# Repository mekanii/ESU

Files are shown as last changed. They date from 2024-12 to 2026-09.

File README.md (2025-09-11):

# 1. General Concept
<p align="center">
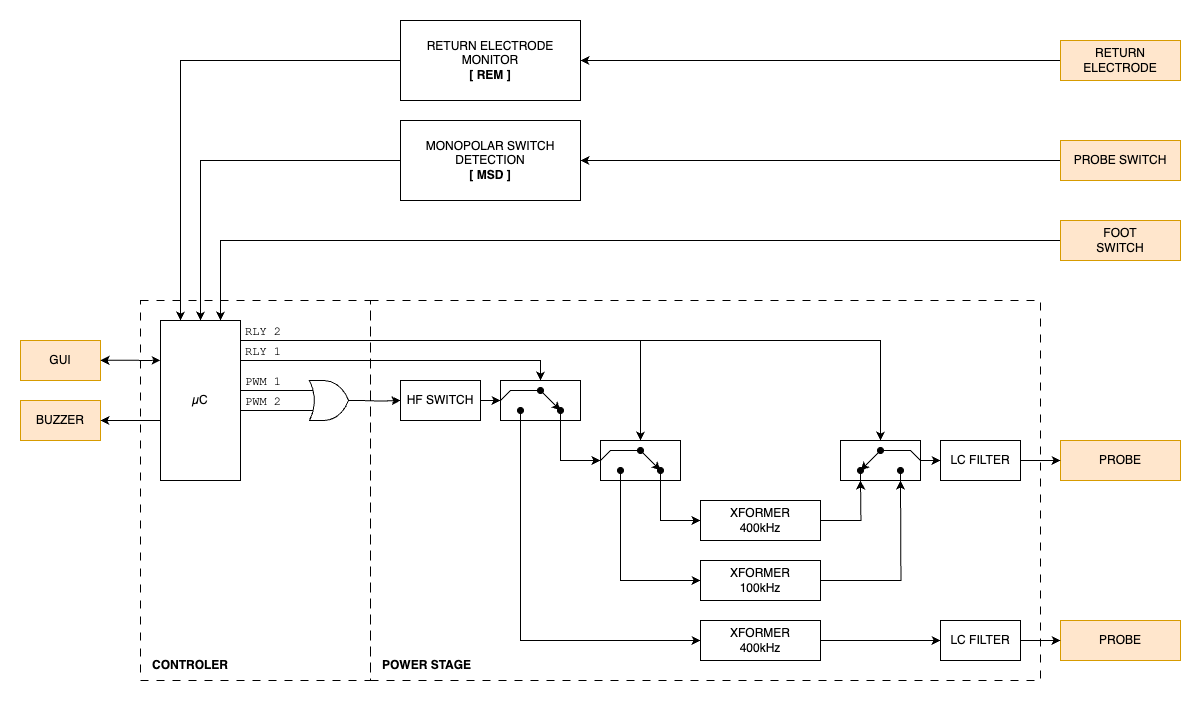
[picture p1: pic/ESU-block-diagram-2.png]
esu-block-diagram
  
</p>

<p align="center">
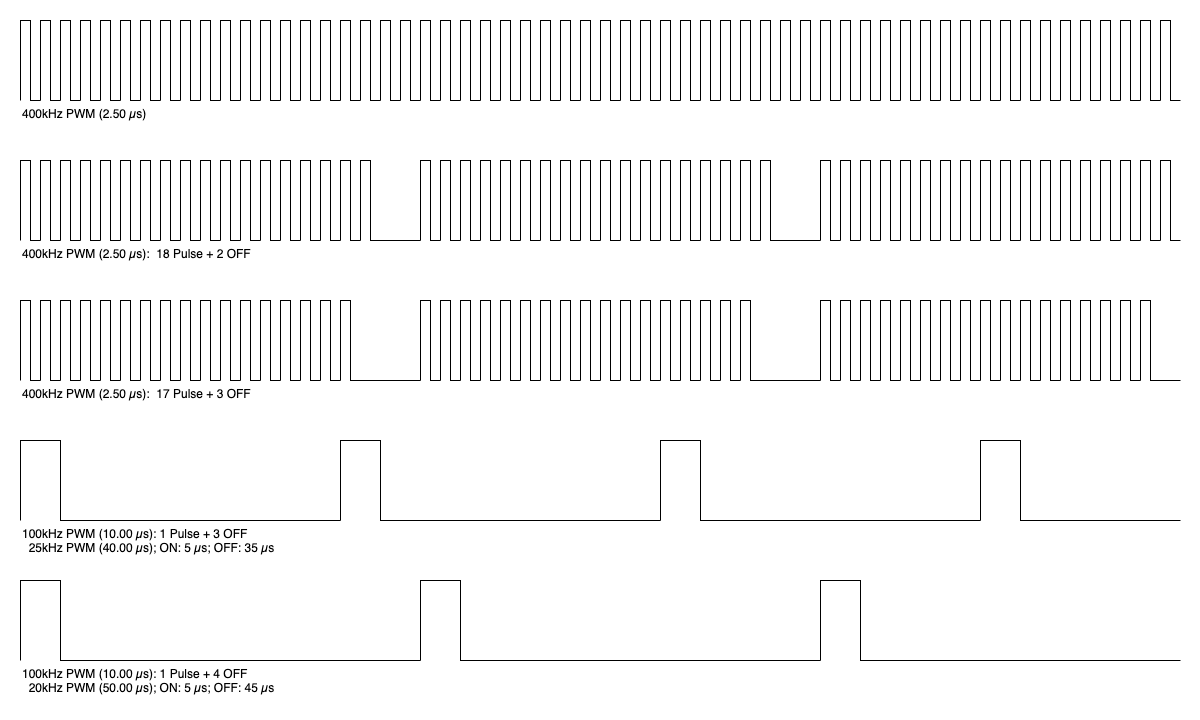
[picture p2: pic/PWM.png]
pwm
  
</p>

# 2. Component
## 2.1. Monopolar Switch Detection (MSD)
### 2.1.1. Schematic

<p align="center">
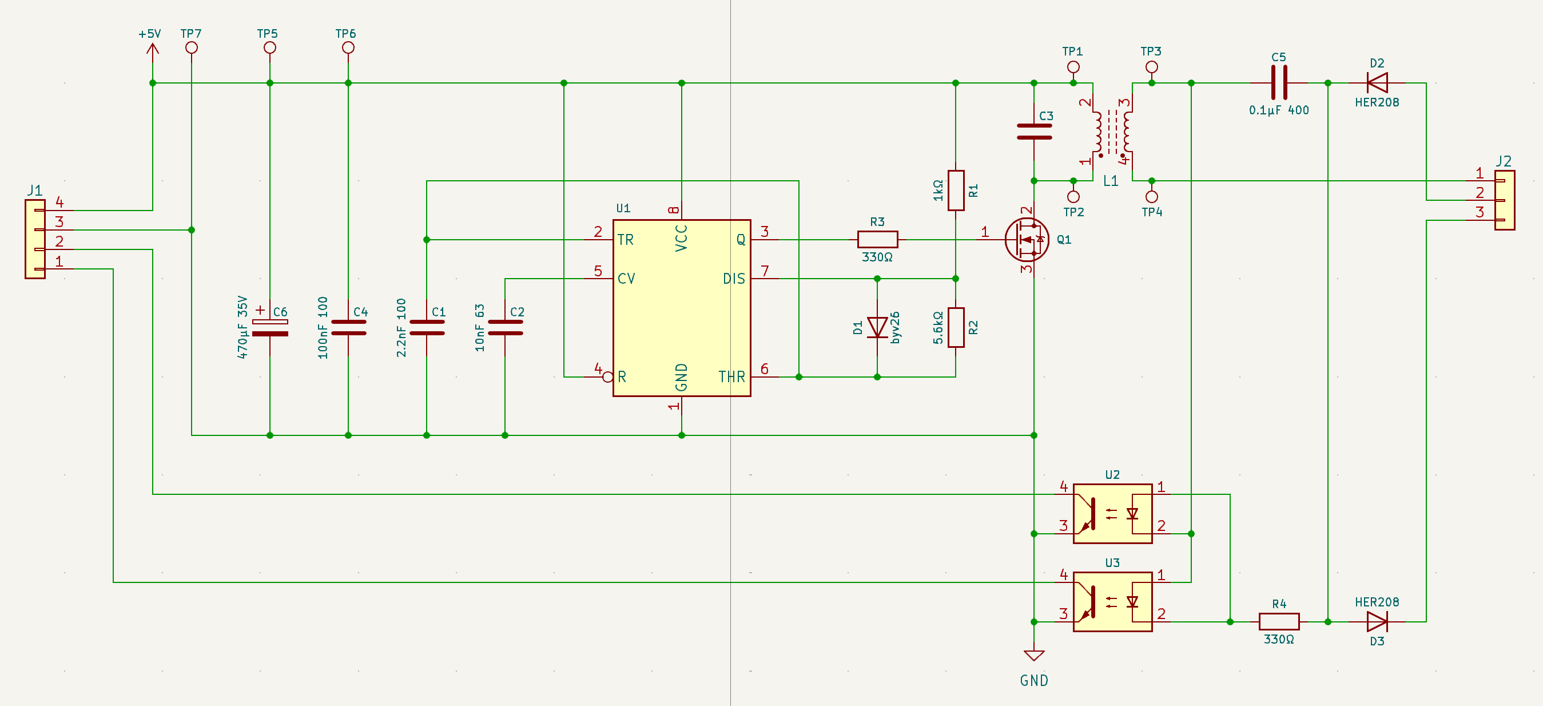
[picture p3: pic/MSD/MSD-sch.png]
msd-sch
  
</p>

### 2.1.2. Output Scope
- Cut
- Coag

## 2.2. Return Electrode Monitor (REM)
### 2.2.1. Schematic

<p align="center">
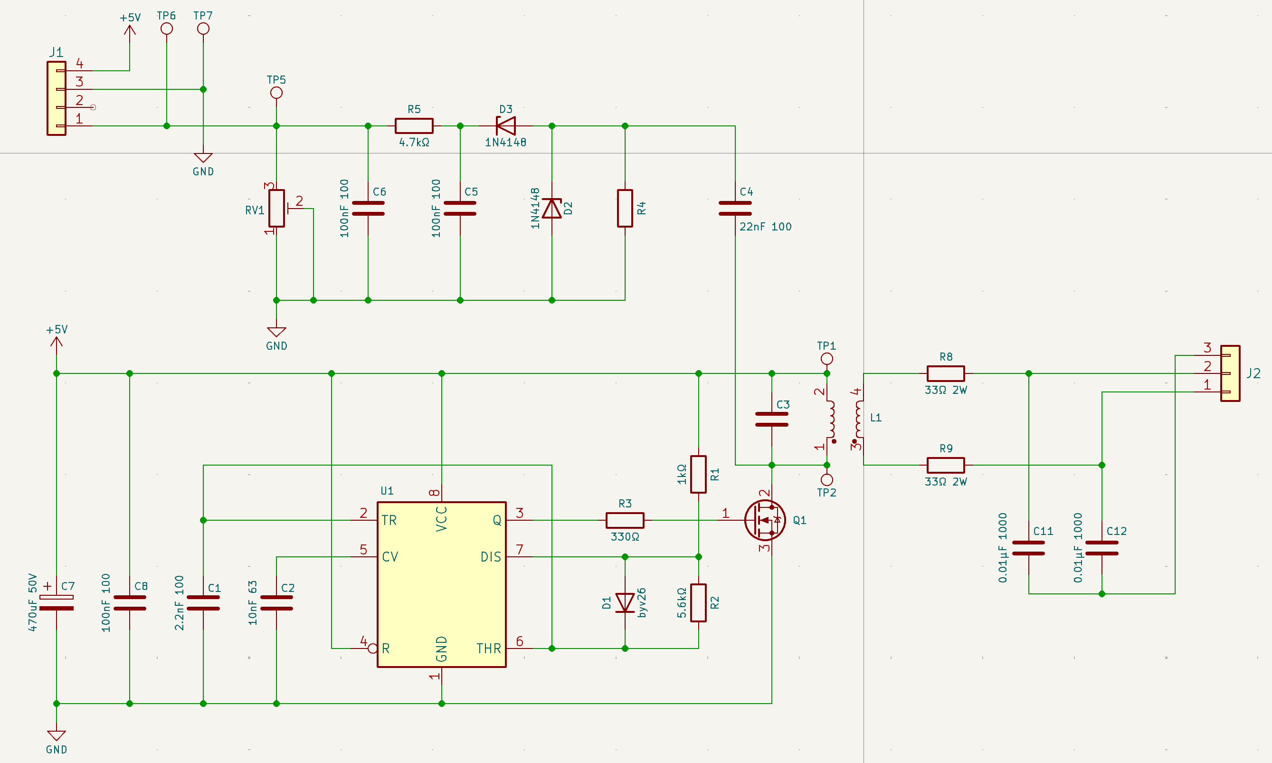
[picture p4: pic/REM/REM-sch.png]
rem-sch
  
</p>

### 2.2.2. Output Scope
#### 2.2.2.1. Transformer
Below is the output scope at the input and output of toroidal transformer.

<p align="center">
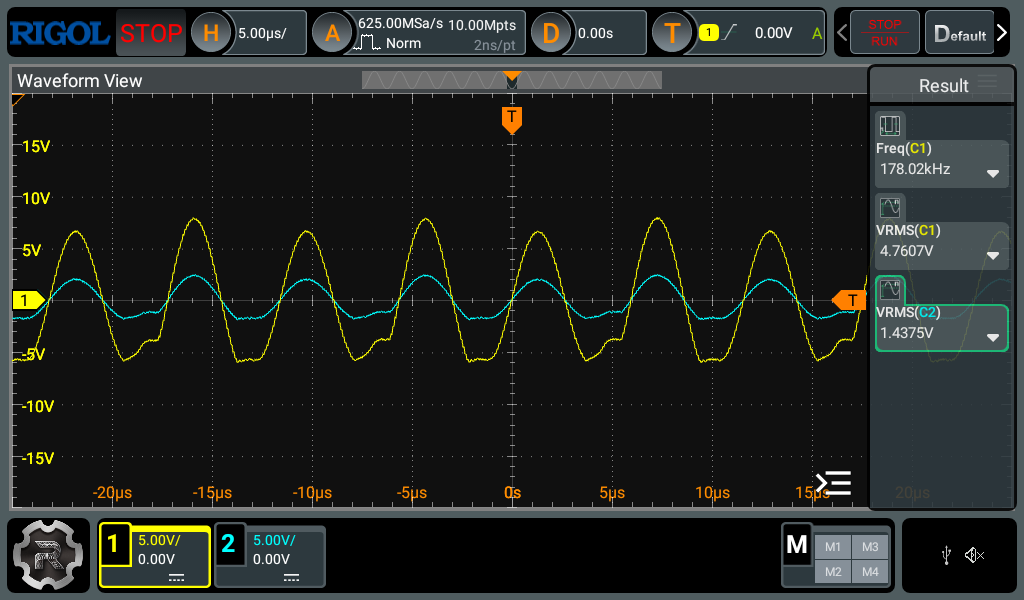
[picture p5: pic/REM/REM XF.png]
rem-xf
  
</p>

#### 2.2.2.2 Sense
> [!NOTE]
> All measurements for Return Electrode Monitoring do not utilize a physical Return Electrode; instead, a variable resistor is used. Therefore, all references to **pad resistance** in this context describe the variable resistor that simulates the Return Electrode.

Below is the output scope from the sense circuit, where the pad resistance values are 5Ω, 200Ω, 1kΩ, and High Impedance. The voltages measured by the oscilloscope are 10.385 mV, 558.91 mV, 689.31 mV, and 1.1164 V, respectively.

<p align="center">
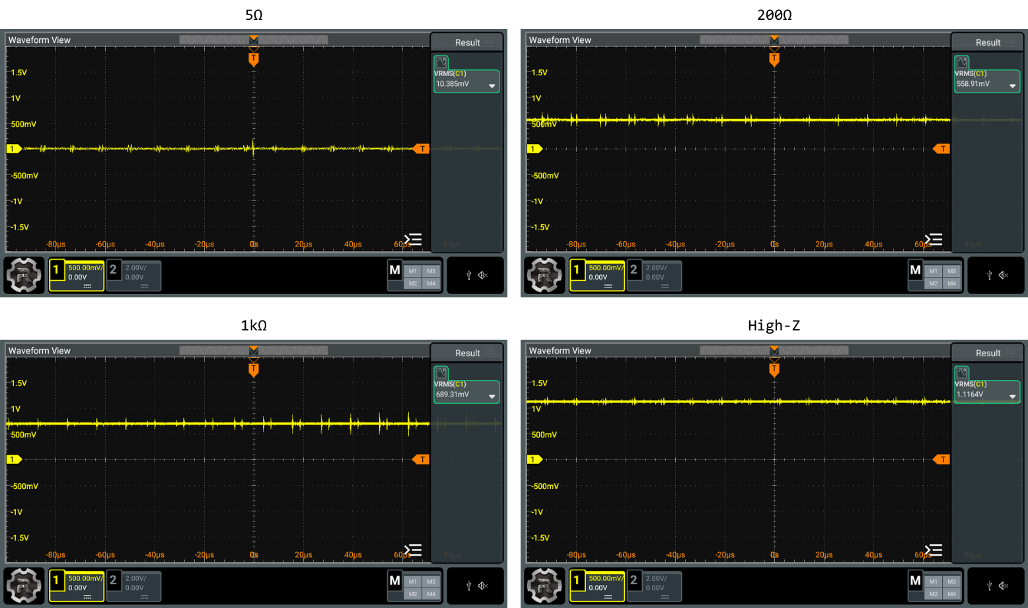
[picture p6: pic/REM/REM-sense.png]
rem-sense
  
</p>

The ESP32's ADC provides a versatile and powerful way to read analog signals with a resolution of up to 12 bits and operates with a reference voltage of 0V to 3.3V (the default voltage range). Below is the formula to calculate the voltage per level for the ADC at 12-bit resolution.

$Voltage \ per \ Level = \frac{Voltage \ Range}{2^{Resolution}} = \frac{3.3V - 0V}{2^{12}} = \frac{3.3V}{4096} ≈ 0.00080586V ≈ 0.80586 mV$

Below is the formula to calculate the ADC value based on the voltage sense and the Voltage per Level.

$ADC \ Value = \frac{V_{sense}}{Voltage \ per \ Level}$

Using the formula above, we have the following ADC values for different pad resistances:

<div align="center">

| Pad Resistance | Measured Voltage | ADC Value |
| ---: | ---: | ---: |
| 5Ω | 10.385 mV | 19 |
| 200Ω | 558.91 mV | 694 |
| 1kΩ | 689.31 mV | 855 |
| High-Z | 1116.4 mV | 1385 |

</div>

## 2.3. Controller
### 2.3.1. PWM Generator
#### 2.3.1.1. Using the Remote Control Module (RMT) of ESP32 for Generating PWM Signals
The Remote Control Module (RMT) on the ESP32 is a versatile hardware peripheral designed primarily for sending and receiving infrared signals. However, it can also be effectively utilized to generate precise Pulse Width Modulation (PWM) signals.

#### 2.3.1.2. Key Concepts
- Duty Cycle:<br>The duty cycle of a PWM signal is the percentage of one cycle in which the signal is high (on) versus low (off). It is typically expressed as a value between 0 and 100.
- Total Period:<br>The total period of the PWM signal is the sum of the HIGH time and LOW time.

#### 2.3.1.3. Configuration
##### a. Clock Divider
The clock divider is a crucial parameter in microcontroller and digital circuit design that determines the frequency of a clock signal by dividing the input clock frequency, which is APB_CLK (80 MHz) for ESP32.

$Clock \ Divider = \frac{APB \_ CLK}{Clock \ Frequency}$

##### b. Resolution
The resolution in duty cycle is a crucial parameter in microcontroller and digital circuit design that determines the granularity of control over the PWM signal. It defines how finely the duty cycle can be adjusted, allowing for precise modulation of the output signal. In the case of the ESP32, the resolution is influenced by the clock frequency which ultimately affect the ability to achieve desired output levels.

$Resolution = \frac{Clock \ Frequency}{PWM \ Frequency}$

##### c. Combination of Clock Frequency and Resolution
The combination of clock frequency and resolution plays a vital role in determining the performance of PWM signals in microcontroller applications. The clock frequency sets the base rate at which the system operates, while the resolution defines how many discrete levels the duty cycle can be divided into. A higher clock frequency allows for faster switching and more precise timing, while a higher resolution enables finer control over the duty cycle. Together, they influence the accuracy and responsiveness of the PWM output, making it essential to balance these parameters to meet the specific requirements of the application.

<div align="center">

| Mode | f PWM | f Clock  | Clock Div | Resolution | 
| --- | ---: | ---: | ---: | ---: |
| Pure Cut |  400 kHz | 80 MHz | 1 | 200 |
| Blend Cut 1 |  400 kHz | 80 MHz | 1 | 200 |
| Blend Cut 2 |  400 kHz | 80 MHz | 1 | 200 |
| Coag Spray | 25 kHz | 10 MHz | 8 | 800 |
| Coag Forced | 20 kHz | 10 MHz | 8 | 1000 |
| Coag Standard |  400 kHz | 80 MHz | 1 | 200 |

</div>

#### 2.3.1.4. Output Scope
##### a. 400kHz
- Pattern 1
<br>The image illustrates the output scope for the Pattern 1 (Pure Cut operation) at the PWM generator. It provides a detailed view of the waveform characteristics and performance metrics associated with the Pure Cut process, highlighting the key features and behavior of the PWM signal during this operation.
<br>For discrete levels ranging from 10 to 100, demonstrates similar PWM frequency, indicating consistent performance across these duty cycle settings.

> [!NOTE]
> 400kHz PWM signal utilize a discrete resolution of 200 levels.

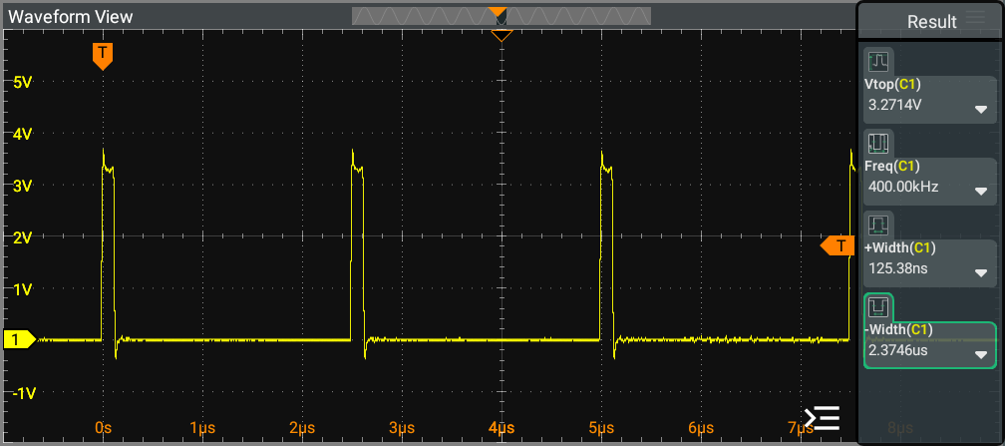
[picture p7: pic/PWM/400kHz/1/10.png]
pwm-400-1-10

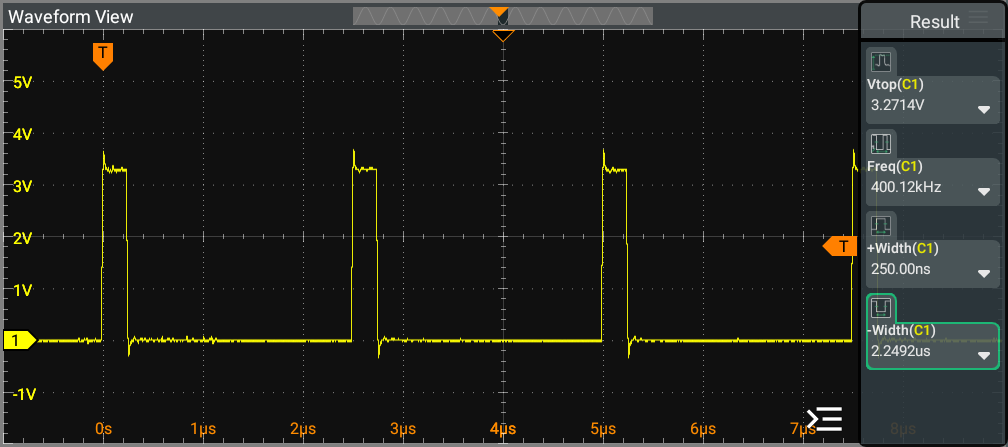
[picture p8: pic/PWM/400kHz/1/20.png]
pwm-400-1-20

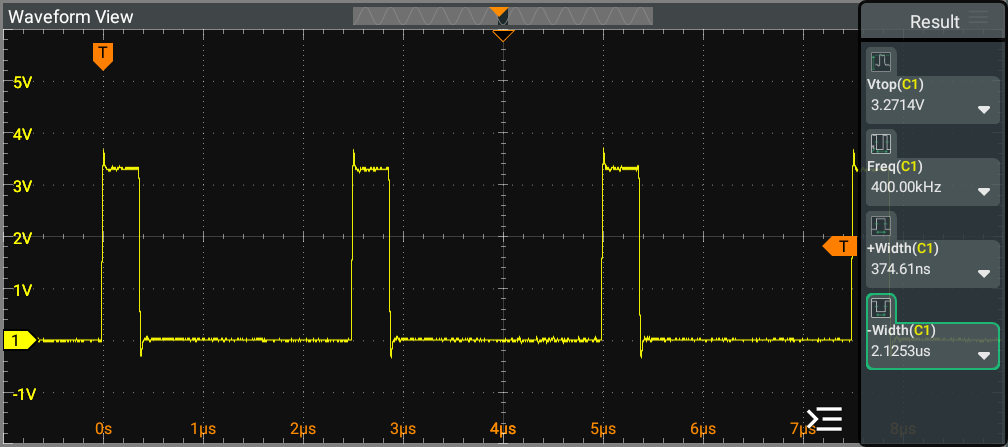
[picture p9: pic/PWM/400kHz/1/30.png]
pwm-400-1-30

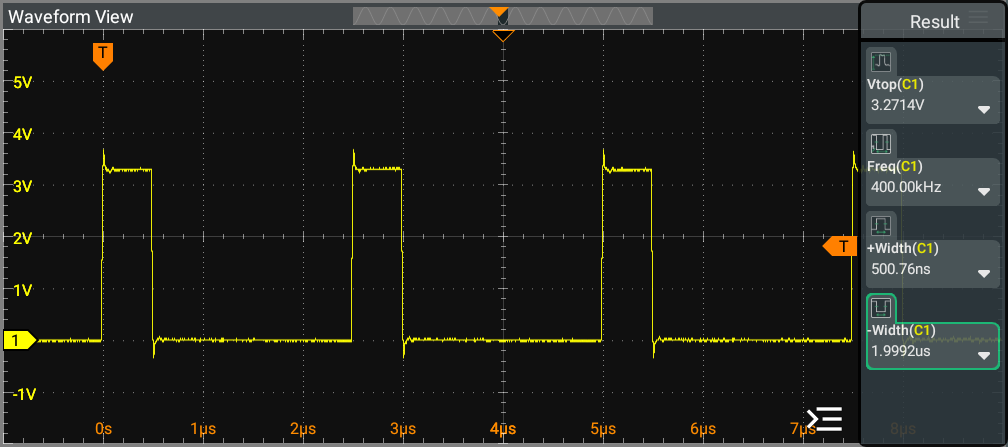
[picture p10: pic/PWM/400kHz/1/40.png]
pwm-400-1-40

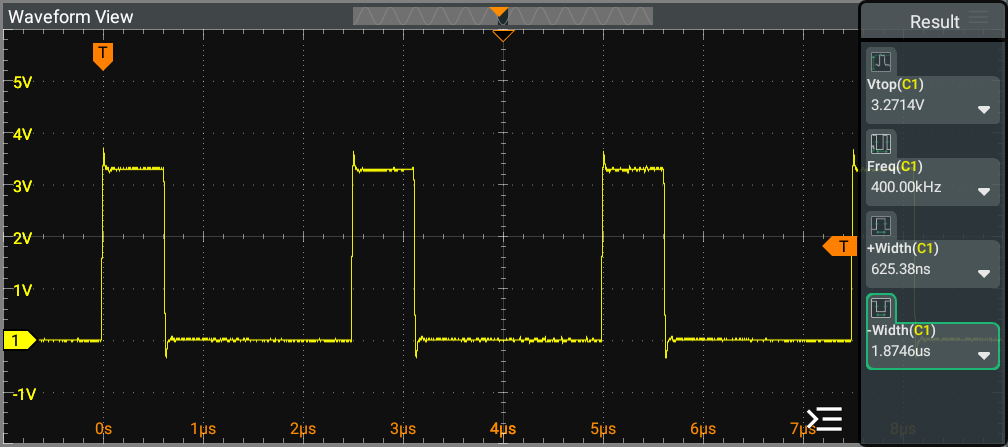
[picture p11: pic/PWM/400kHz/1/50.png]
pwm-400-1-50

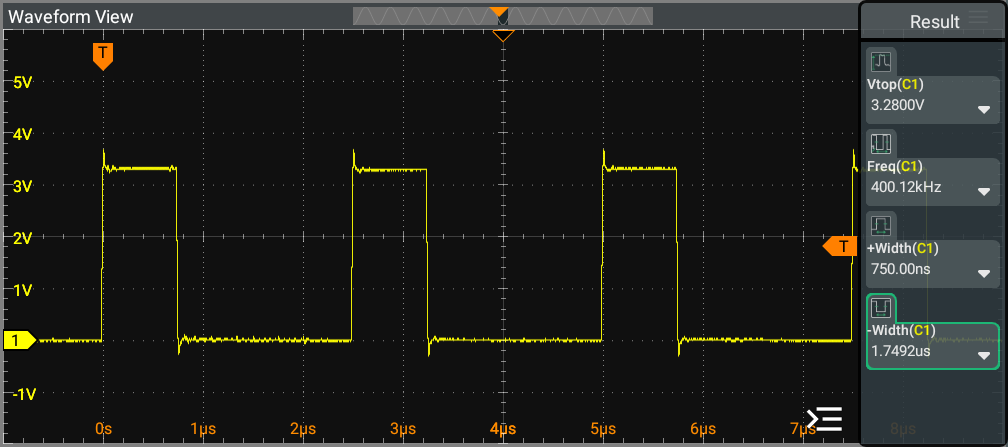
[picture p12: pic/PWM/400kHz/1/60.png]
pwm-400-1-60

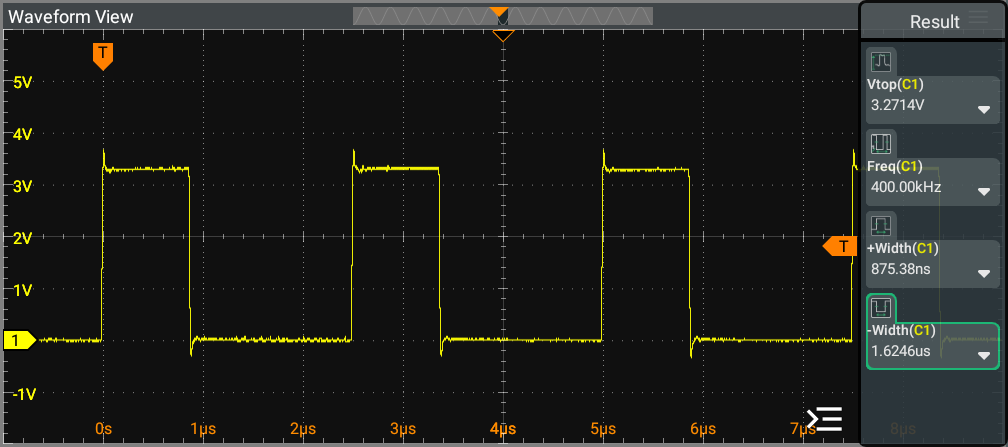
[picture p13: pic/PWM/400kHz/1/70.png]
pwm-400-1-70

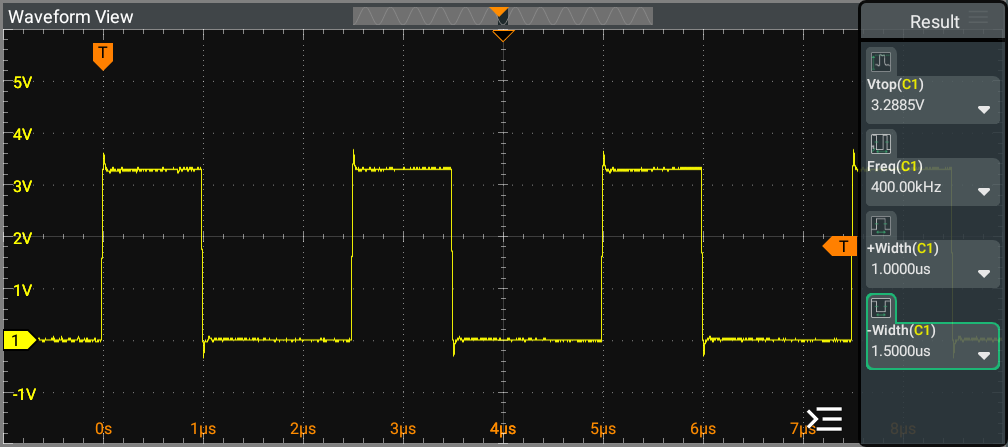
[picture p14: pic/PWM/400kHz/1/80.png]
pwm-400-1-80

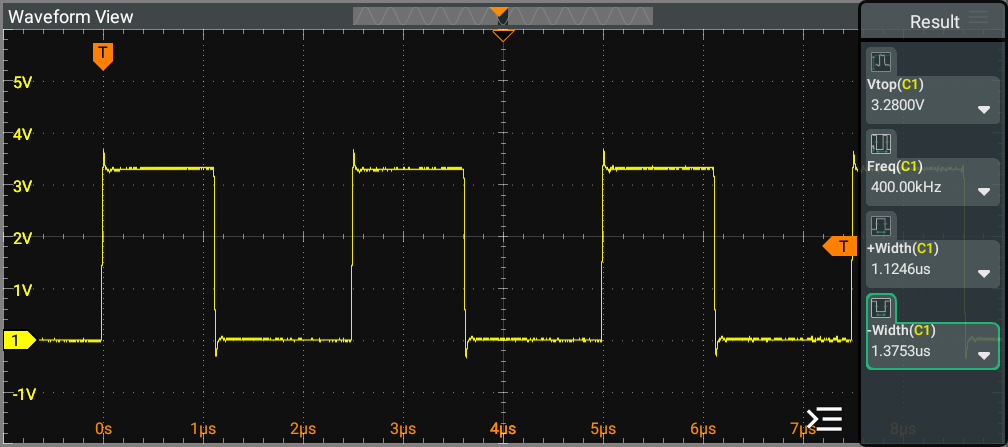
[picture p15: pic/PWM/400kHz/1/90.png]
pwm-400-1-90

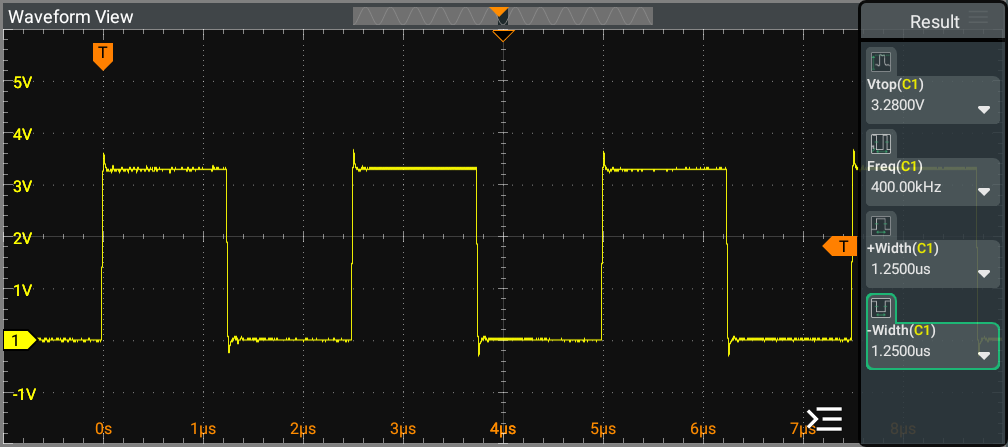
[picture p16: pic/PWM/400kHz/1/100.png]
pwm-400-1-100


<!-- <p align="center">
  <img src="pic/PWM/PWM-pure-cut.png" alt="PWM-pure-cut">
</p> -->

- Pattern 2<br>
The image illustrates the output scope for the Pattern 2 (Blend Cut 1) operation at the PWM generator. It provides a detailed view of the waveform characteristics and performance metrics associated with the Blend Cut process, highlighting the key features and behavior of the PWM signal during this operation.<br>
For discrete levels ranging from 10 to 100, demonstrates similar PWM frequency and similar waveform HIGH state periods, indicating consistent performance across these duty cycle settings. Each pulse in Blend Cut 1 is similar to a single pulse of a Pattern 1 (Pure Cut) PWM signal.

> [!NOTE]
> Pattern 2: 18 pulses per 1 modulation (400 kHz for each pulse, with 0% PWM during the last 2 periods).<br>This pattern utilize a discrete resolution of 200 levels, similar to that of a Pattern 1 (Pure Cut) PWM signal.

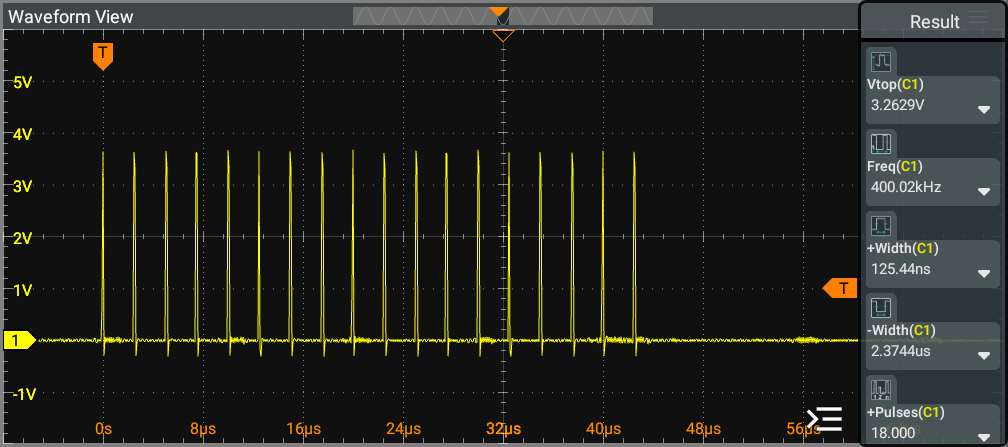
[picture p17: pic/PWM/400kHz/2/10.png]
pwm-400-2-10

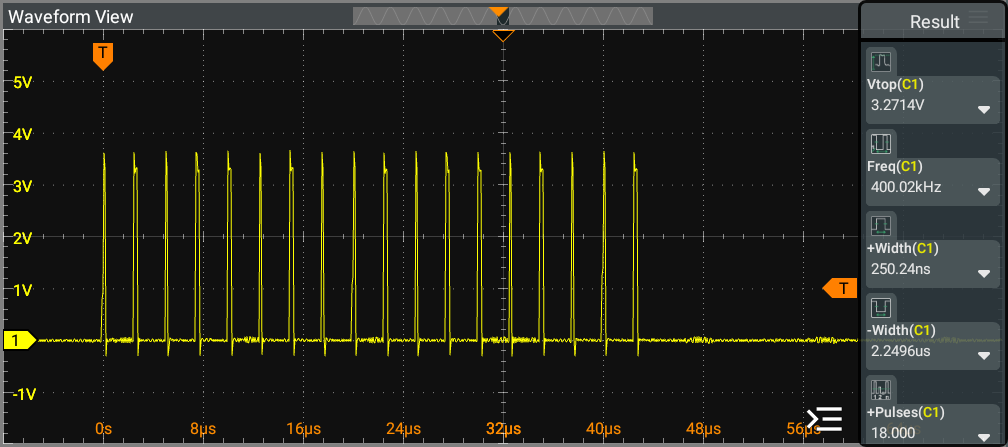
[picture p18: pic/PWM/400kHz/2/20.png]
pwm-400-2-20

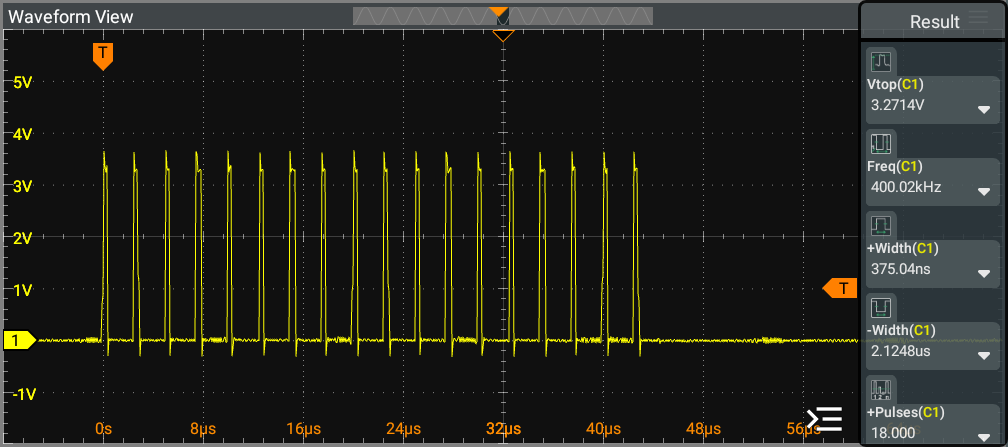
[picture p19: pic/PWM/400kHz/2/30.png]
pwm-400-2-30

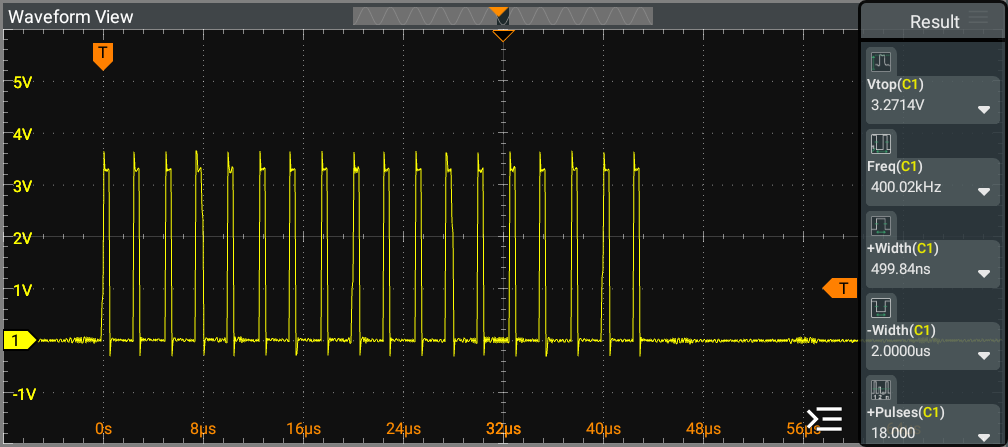
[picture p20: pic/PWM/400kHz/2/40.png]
pwm-400-2-40

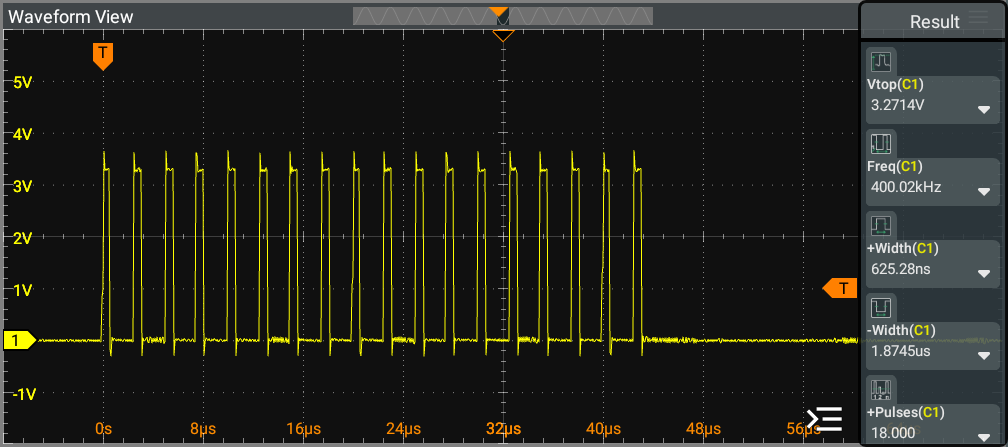
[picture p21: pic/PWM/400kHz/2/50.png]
pwm-400-2-50

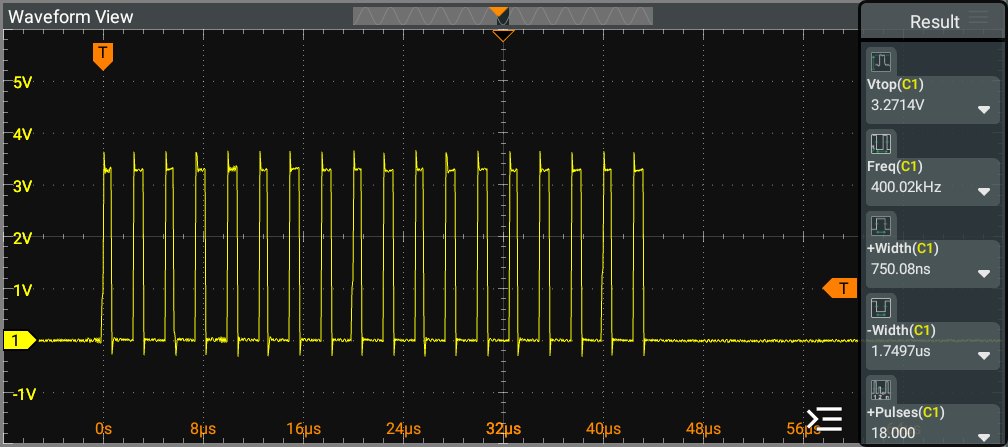
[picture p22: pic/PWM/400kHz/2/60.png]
pwm-400-2-60

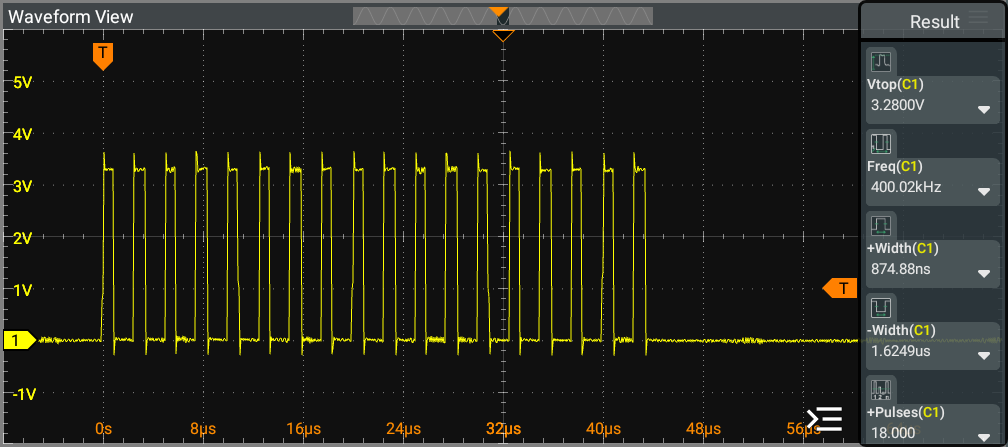
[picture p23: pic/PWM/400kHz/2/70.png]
pwm-400-2-70

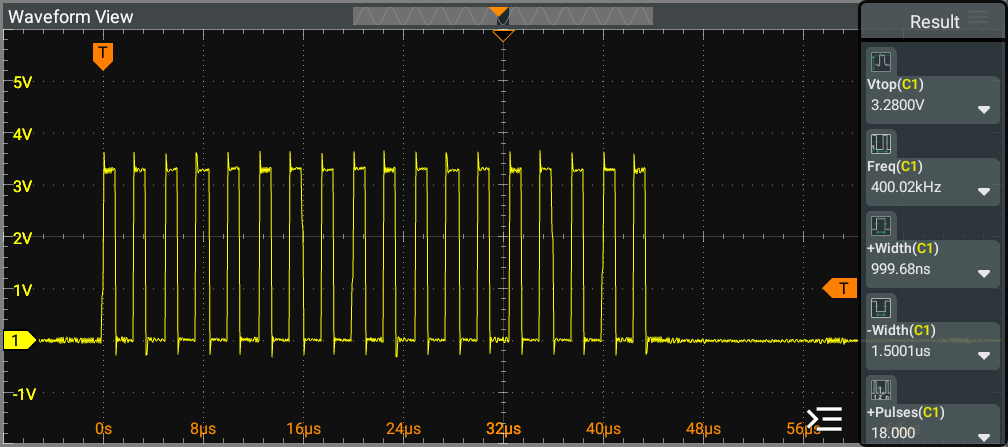
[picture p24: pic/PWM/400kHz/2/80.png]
pwm-400-2-80

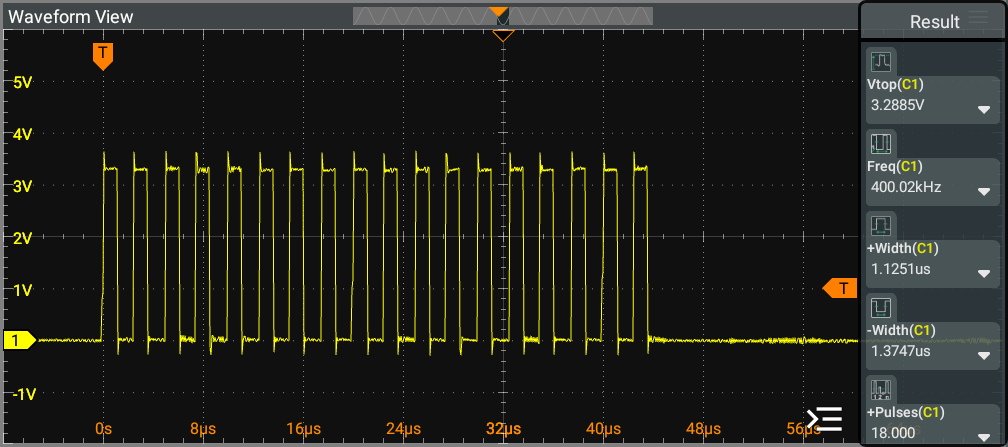
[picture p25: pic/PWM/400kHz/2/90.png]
pwm-400-2-90

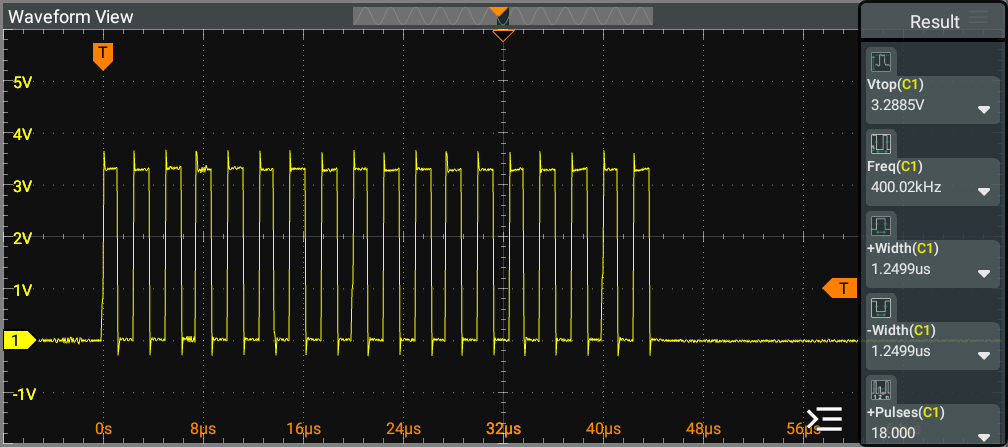
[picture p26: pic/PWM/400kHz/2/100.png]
pwm-400-2-100


- Pattern 3
<br>The image illustrates the output scope for the Pattern 3 (Blend Cut 2) operation at the PWM generator. It provides a detailed view of the waveform characteristics and performance metrics associated with the Blend Cut process, highlighting the key features and behavior of the PWM signal during this operation.
<br>For discrete levels ranging from 10 to 100, demonstrates similar PWM frequency and similar waveform HIGH state periods, indicating consistent performance across these duty cycle settings. Each pulse in Blend Cut 2 is similar to a single pulse of a Pure Cut PWM signal.

> [!NOTE]
> Pattern 3: 17 pulses per 1 modulation (400 kHz for each pulse, with 0% PWM during the last 3 periods).<br>This pattern utilize a discrete resolution of 200 levels, similar to that of a Pattern 1 (Pure Cut) PWM signal.

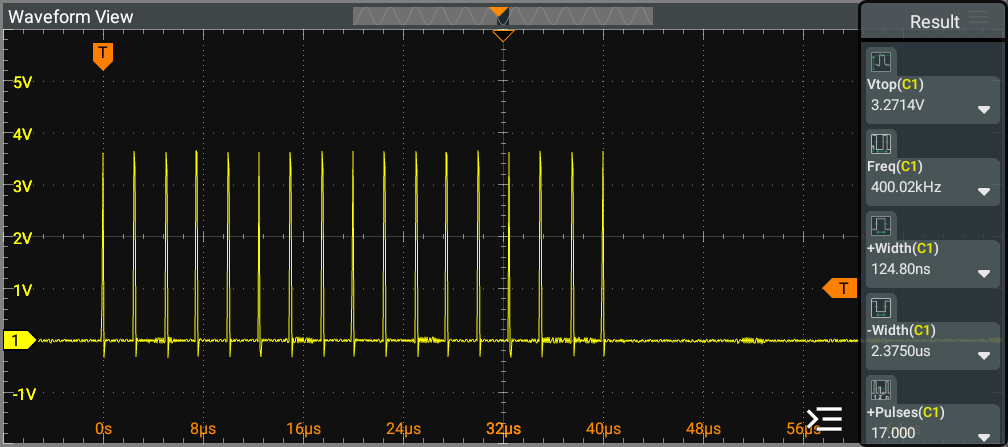
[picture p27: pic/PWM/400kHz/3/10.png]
pwm-400-3-10

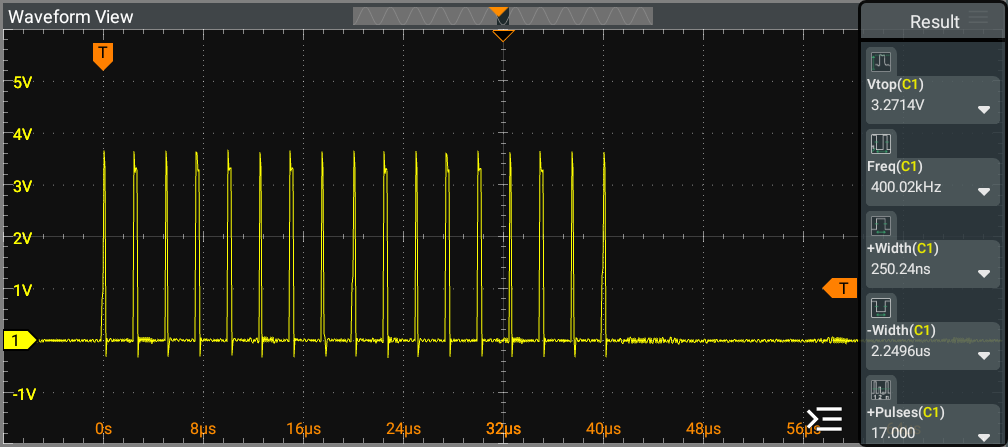
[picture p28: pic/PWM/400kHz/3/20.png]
pwm-400-3-20

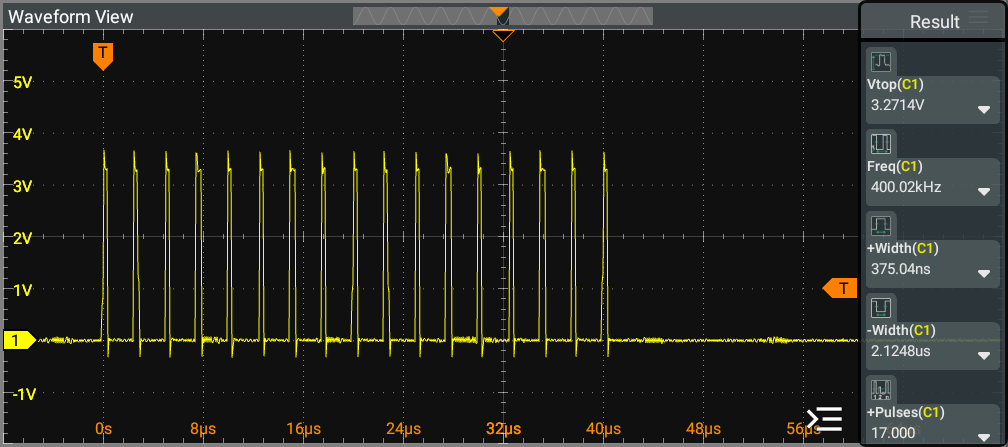
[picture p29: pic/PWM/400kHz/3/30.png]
pwm-400-3-30

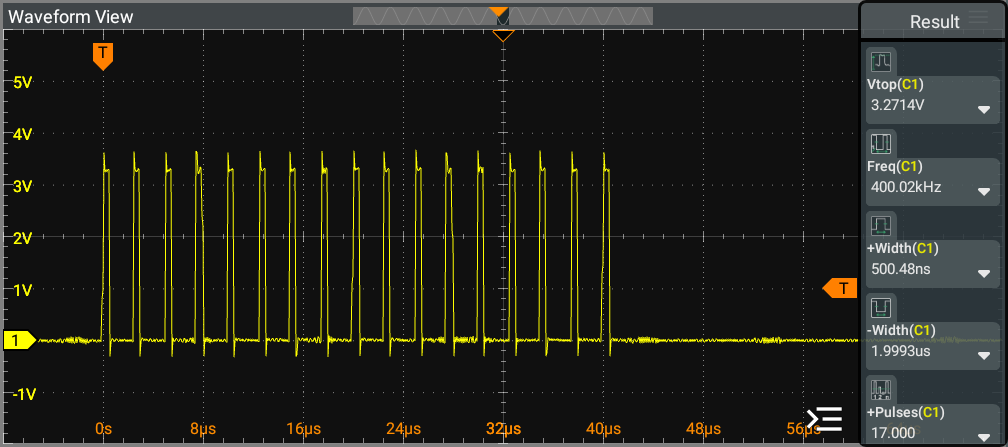
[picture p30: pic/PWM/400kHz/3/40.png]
pwm-400-3-40

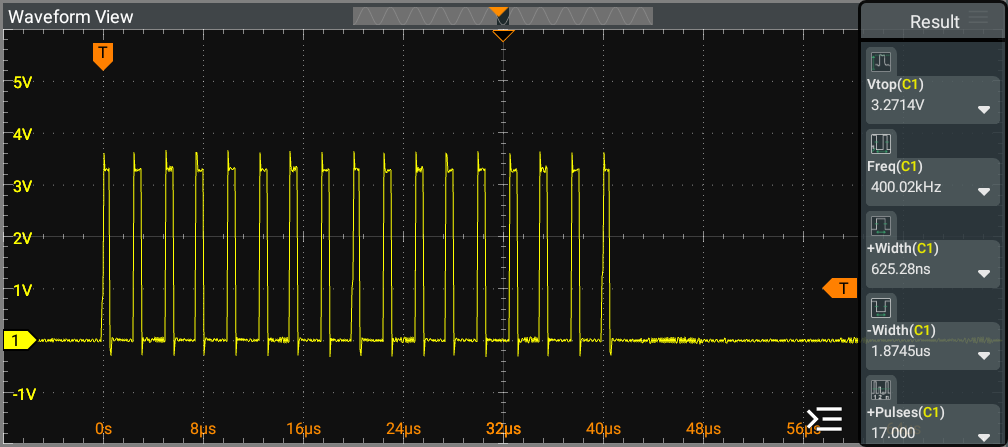
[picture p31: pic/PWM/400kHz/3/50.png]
pwm-400-3-50

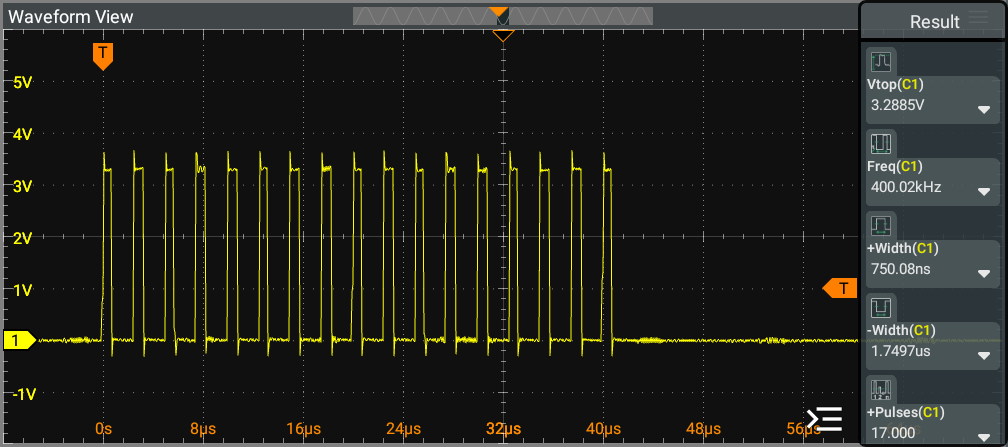
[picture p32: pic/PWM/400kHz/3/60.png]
pwm-400-3-60

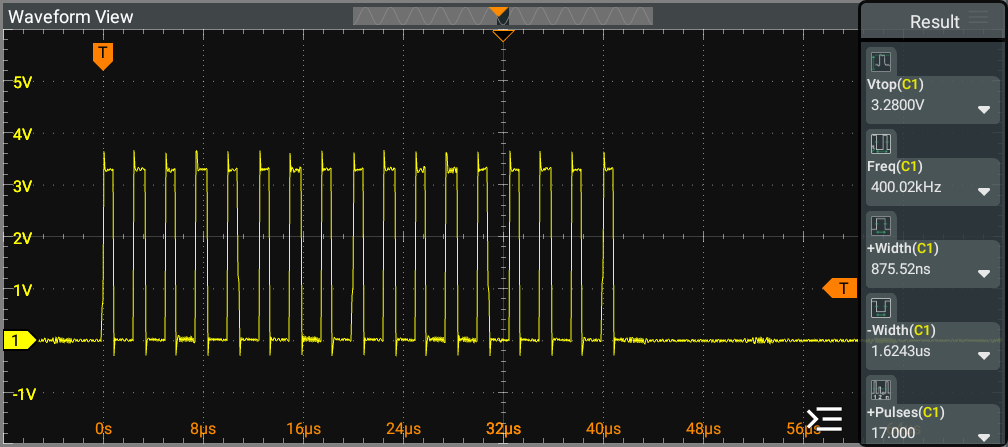
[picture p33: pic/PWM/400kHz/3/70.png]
pwm-400-3-70

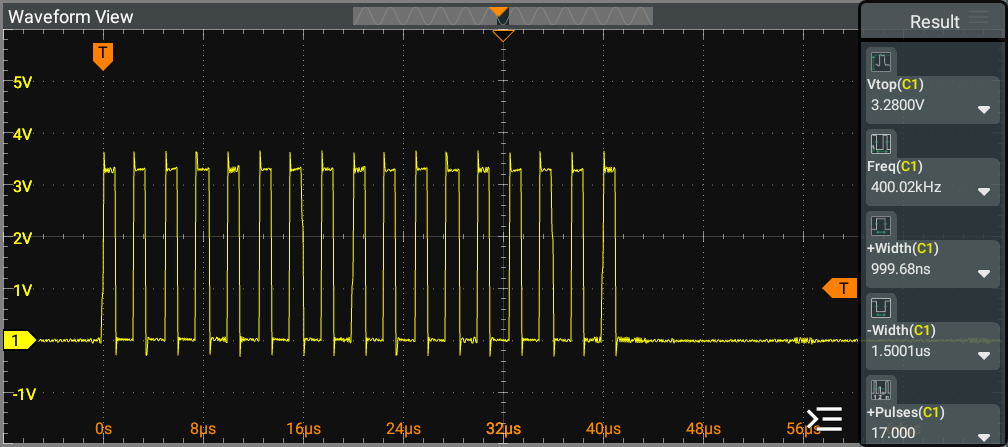
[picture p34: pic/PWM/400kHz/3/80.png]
pwm-400-3-80

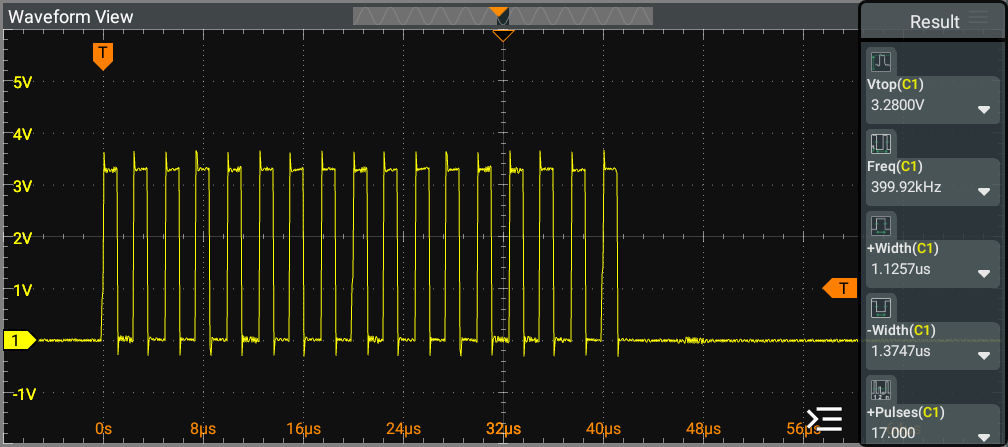
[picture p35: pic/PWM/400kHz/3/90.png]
pwm-400-3-90

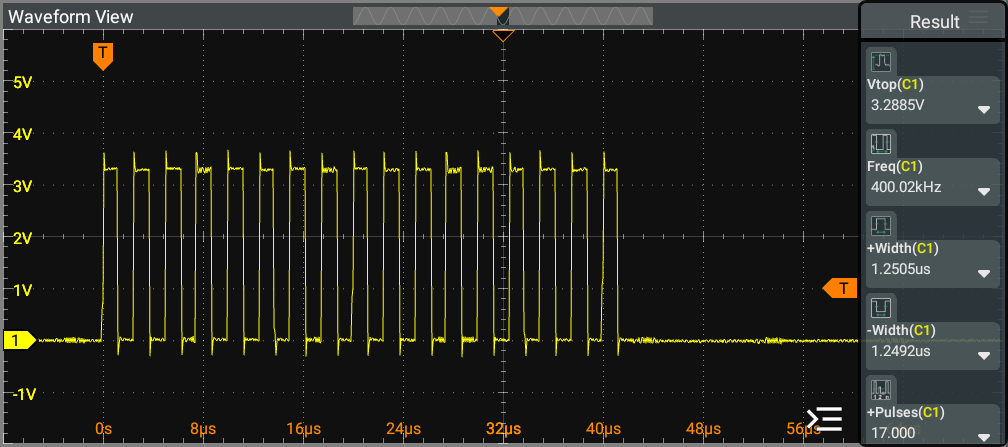
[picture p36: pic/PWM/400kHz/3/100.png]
pwm-400-3-100


<!-- <p align="center">
  <img src="pic/PWM/PWM-blend-cut.png" alt="PWM-blend-cut">
</p> -->

##### b. 25kHz
The image illustrates the output scope for the 25kHz (Spray Coagulation operation) at the PWM generator. It provides a detailed view of the waveform characteristics and performance metrics associated with the Spray Coagulation process, highlighting the key features and behavior of the PWM signal during this operation.

For discrete levels ranging from 10 to 100, demonstrates similar PWM frequency, indicating consistent performance across these duty cycle settings. We can observe that the increment of the duty cycle results in a pulse that exhibits a linear increase in HIGH time, further emphasizing the effectiveness of the PWM modulation in maintaining a predictable response across varying duty cycle levels.

> [!NOTE]
> 25kHz PWM signal utilize a discrete resolution of 800 levels.

<p align="center">
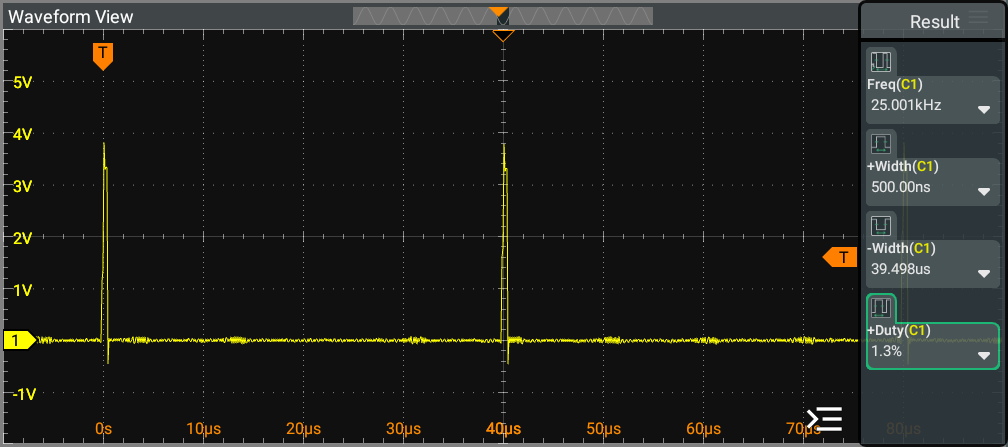
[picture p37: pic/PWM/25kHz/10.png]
pwm-25-10
  
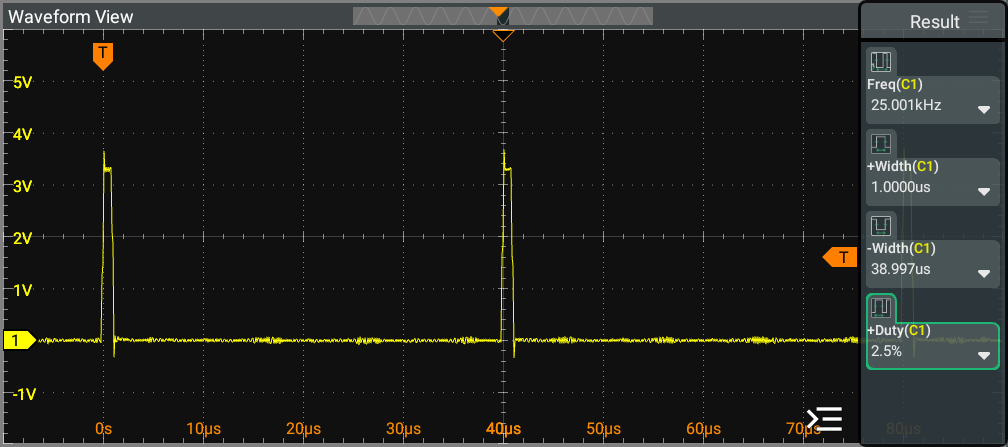
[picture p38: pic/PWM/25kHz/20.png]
pwm-25-20
  
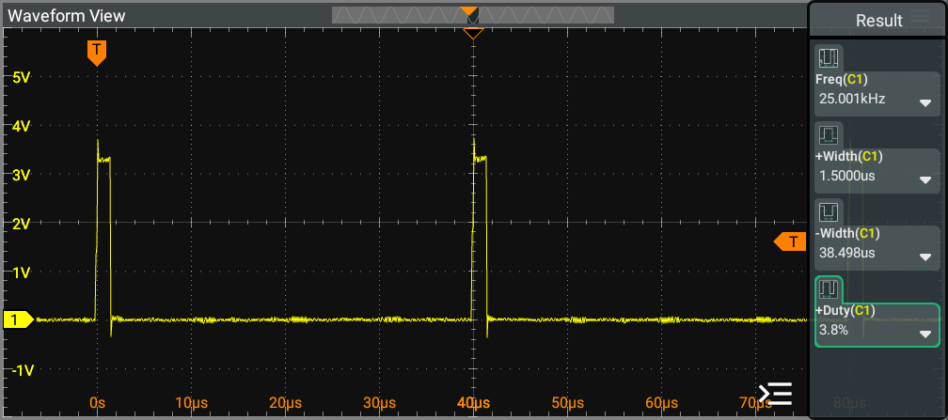
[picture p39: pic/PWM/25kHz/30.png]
pwm-25-30
  
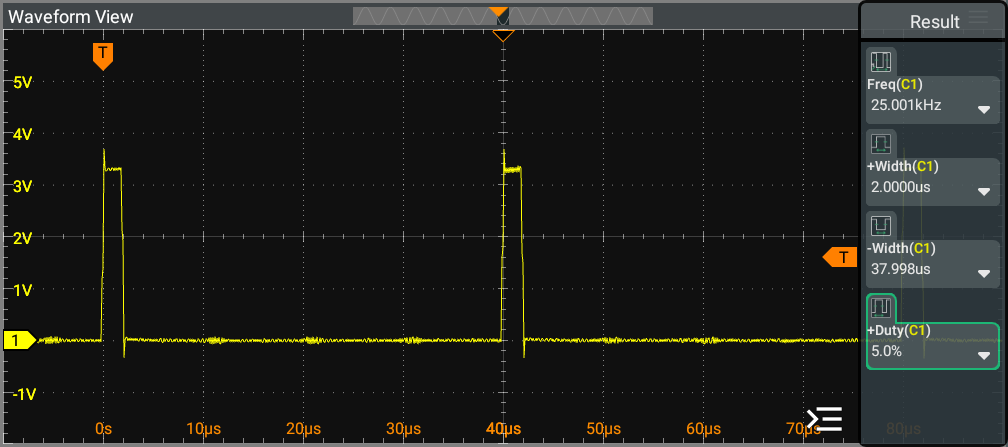
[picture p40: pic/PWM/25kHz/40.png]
pwm-25-40
  
  <p align="center">pwm-25-50</p>
  <p align="center">pwm-25-60</p>
  <p align="center">pwm-25-70</p>
  <p align="center">pwm-25-80</p>
  <p align="center">pwm-25-90</p>
  <p align="center">pwm-25-100</p>
</p>

<div align="center">

| Discrete Level  | Duty Cycle  | HIGH Time | LOW Time  |
| ---:| ---:| ---:| ---:|
| 10 | 1.25 % | 0.5 µs | 39.5 µs |
| 20 | 2.50 % | 1.0 µs | 39.0 µs |
| 30 | 3.75 % | 1.5 µs | 38.5 µs |
| 40 | 5.00 % | 2.0 µs | 38.0 µs |
| 50 | 6.25 % | 2.5 µs | 37.5 µs |
| 60 | 7.50 % | 3.0 µs | 37.0 µs |
| 70 | 8.75 % | 3.5 µs | 36.5 µs |
| 80 | 10.00 % | 4.0 µs | 36.0 µs |
| 90 | 11.25 % | 4.5 µs | 35.5 µs |
| 100 | 12.50 % | 5.0 µs | 35.0 µs |

</div>

##### c. 20kHz
The image illustrates the output scope for the 20kHz (Forced Coagulation operation) at the PWM generator. It provides a detailed view of the waveform characteristics and performance metrics associated with the Forced Coagulation process, highlighting the key features and behavior of the PWM signal during this operation.

For discrete levels ranging from 10 to 100, demonstrates similar PWM frequency, indicating consistent performance across these duty cycle settings. We can observe that the increment of the duty cycle results in a pulse that exhibits a linear increase in HIGH time, further emphasizing the effectiveness of the PWM modulation in maintaining a predictable response across varying duty cycle levels.

> [!NOTE]
> 20kHz PWM signal utilize a discrete resolution of 1000 levels.

<p align="center">
  <p align="center">pwm-20-10</p>
  <p align="center">pwm-20-20</p>
  <p align="center">pwm-20-30</p>
  <p align="center">pwm-20-40</p>
  <p align="center">pwm-20-50</p>
  <p align="center">pwm-20-60</p>
  <p align="center">pwm-20-70</p>
  <p align="center">pwm-20-80</p>
  <p align="center">pwm-20-90</p>
  <p align="center">pwm-20-100</p>
</p>

<div align="center">

| Discrete Level  | Duty Cycle  | HIGH Time | LOW Time  |
| ---:| ---:| ---:| ---:|
| 10 | 1.00 % | 0.5 µs | 49.5 µs |
| 20 | 2.00 % | 1.0 µs | 49.0 µs |
| 30 | 3.00 % | 1.5 µs | 48.5 µs |
| 40 | 4.00 % | 2.0 µs | 48.0 µs |
| 50 | 5.00 % | 2.5 µs | 47.5 µs |
| 60 | 6.00 % | 3.0 µs | 47.0 µs |
| 70 | 7.00 % | 3.5 µs | 46.5 µs |
| 80 | 8.00 % | 4.0 µs | 46.0 µs |
| 90 | 9.00 % | 4.5 µs | 45.5 µs |
| 100 | 10.00 % | 5.0 µs | 45.0 µs |

</div>

### 2.3.2. Communication Protocol
<!-- 0x5000-0x7FFF can be used as the variable address range; 0x8000-0xFFFF -->
The system UART mode is fixed to 8N1, and the baud rate is 115200.

**Frame Structure**

The data frame consists of 5 data blocks:

```[HEADER] [LENGTH] [INSTRUCTION] [PAYLOAD] [CRC]```

**Frame Components**

<table>
  <thead>
    <tr>
      <td>Block</td>
      <td>Size [byte]</td>
      <td>Description</td>
      <td>Value</td>
    </tr>
  </thead>
  <tbody>
    <tr>
      <td>HEADER</td>
      <td>2</td>
      <td>Frame start marker</td>
      <td>0x5A 0XA5</td>
    </tr>
    <tr>
      <td>LENGTH</td>
      <td>1</td>
      <td>Total bytes after HEADER</td>
      <td>INSTRUCTION + DATA + CRC</td>
    </tr>
    <tr>
      <td>INSTRUCTION</td>
      <td>1</td>
      <td>Instruction Code</td>
      <td>0x82 : Write<br>0x83 : Read</td>
    </tr>
    <tr>
      <td>PAYLOAD</td>
      <td>0 - 3</td>
      <td>Payload data</td>
      <td></td>
    </tr>
    <tr>
      <td>CRC</td>
      <td>2</td>
      <td>Cyclic Redundancy Check</td>
      <td></td>
    </tr>
  </tbody>
</table>

The `PAYLOAD` frame consist 3 data blocks:

```[VP ADDRESS] [NUMBER OF WORDS] [DATA]```

<table>
  <thead>
    <tr>
      <td>Block</td>
      <td>Size [byte]</td>
      <td>Description</td>
    </tr>
  </thead>
  <tbody>
    <tr>
      <td>VP ADDRESS</td>
      <td>2</td>
      <td>Variable Pointer address to read from</td>
    </tr>
    <tr>
      <td>NUMBER OF WORDS</td>
      <td>1</td>
      <td>Number of data words to read (always 1)</td>
    </tr>
    <tr>
      <td>DATA</td>
      <td>2</td>
      <td>Data word read from the specified VP address</td>
    </tr>
  </tbody>
</table>

#### 2.3.2.1. Basic System Operations

<table>
  <thead>
    <tr>
      <td nowrap>Command</td>
      <td nowrap>Variable</td>
      <td nowrap>VP ADDRESS</td>
      <td>INSTRUCTION</td>
      <td nowrap>Data Frame</td>
      <td nowrap>Response</td>
    </tr>
  </thead>
  <tbody>
    <tr></tr>
    <tr>
      <td nowrap>System status query</td>
      <td><pre>(byte) vp_50[0]</pre></td>
      <td><pre>50 00</pre></td>
      <td><pre>83</pre></td>
      <td><pre>5A A5 08 [INSTRUCTION] 50 00 01 [DATA:H DATA:L] CRC:L CRC:H</pre></td>
      <td nowrap></td>
    </tr>
    <tr></tr>
    <tr>
      <td nowrap>System reset</td>
      <td><pre>(byte) vp_50[1]</pre></td>
      <td><pre>50 01</pre></td>
      <td><pre>82</pre></td>
      <td><pre>5A A5 08 [INSTRUCTION] 50 01 01 [DATA:H DATA:L] CRC:L CRC:H</pre></td>
      <td nowrap></td>
    </tr>
    <tr></tr>
    <tr>
      <td nowrap>Stop all RMT transmission</td>
      <td><pre>(byte) vp_50[2]</pre></td>
      <td><pre>50 02</pre></td>
      <td><pre>82</pre></td>
      <td><pre>5A A5 08 [INSTRUCTION] 50 02 01 [DATA:H DATA:L] CRC:L CRC:H</pre></td>
      <td nowrap></td>
    </tr>
  </tbody>
</table>

#### 2.3.2.2. Mode Selection
<table>
  <thead>
    <tr>
      <td nowrap>Command</td>
      <td nowrap>Variable</td>
      <td nowrap>VP ADDRESS</td>
      <td>INSTRUCTION</td>
      <td nowrap>Data Frame</td>
      <td nowrap>DATA</td>
      <td nowrap>Response</td>
    </tr>
  </thead>
  <tbody>
    <tr></tr>
    <tr>
      <td nowrap>Get/set mode selection Cut</td>
      <td><pre>(int) vp_51[0]</pre></td>
      <td><pre>51 00</pre></td>
      <td><pre>82 | 83</pre></td>
      <td><pre>5A A5 08 [INSTRUCTION] 51 00 01 [DATA:H DATA:L] CRC:L CRC:H</pre></td>
      <td nowrap>
        <pre>0: 400kHz - Pattern 1
1: 400kHz - Pattern 2
2: 400kHz - Pattern 3</pre>
      </td>
      <td nowrap></td>
    </tr>
    <tr></tr>
    <tr>
      <td nowrap>Get/set mode selection Coag</td>
      <td><pre>(int) vp_51[1]</pre></td>
      <td><pre>51 01</pre></td>
      <td><pre>82 | 83</pre></td>
      <td><pre>5A A5 08 [INSTRUCTION] 51 01 01 [DATA:H DATA:L] CRC:L CRC:H</pre></td>
      <td nowrap>
        <pre>0: 25kHz
1: 20kHz
2: 400kHz - Bipolar Standard</pre>
      </td>
      <td nowrap></td>
    </tr>
  </tbody>
</table>

#### 2.3.2.2. Discrete Level Adjustment
<table>
  <thead>
    <tr>
      <td nowrap>Command</td>
      <td nowrap>Variable</td>
      <td nowrap>VP ADDRESS</td>
      <td>INSTRUCTION</td>
      <td nowrap>Data Frame</td>
      <td nowrap>DATA</td>
      <td nowrap>Response</td>
    </tr>
  </thead>
  <tbody>
    <tr></tr>
    <tr>
      <td nowrap>Get/set discrete level 400kHz - Pattern 1</td>
      <td><pre>(int) vp_52[0]</pre></td>
      <td><pre>52 00</pre></td>
      <td><pre>82 | 83</pre></td>
      <td><pre>5A A5 08 [INSTRUCTION] 52 00 01 [DATA:H DATA:L] CRC:L CRC:H</pre></td>
      <td nowrap><pre>0 - 200</pre></td>
      <td nowrap></td>
    </tr>
    <tr></tr>
    <tr>
      <td nowrap>Get/set discrete level 400kHz - Pattern 2</td>
      <td><pre>(int) vp_52[1]</pre></td>
      <td><pre>52 01</pre></td>
      <td><pre>82 | 83</pre></td>
      <td><pre>5A A5 08 [INSTRUCTION] 52 01 01 [DATA:H DATA:L] CRC:L CRC:H</pre></td>
      <td nowrap><pre>0 - 200</pre></td>
      <td nowrap></td>
    </tr>
    <tr></tr>
    <tr>
      <td nowrap>Get/set discrete level 400kHz - Pattern 3</td>
      <td><pre>(int) vp_52[3]</pre></td>
      <td><pre>52 02</pre></td>
      <td><pre>82 | 83</pre></td>
      <td><pre>5A A5 08 [INSTRUCTION] 52 03 01 [DATA:H DATA:L] CRC:L CRC:H</pre></td>
      <td nowrap><pre>0 - 200</pre></td>
      <td nowrap></td>
    </tr>
    <tr></tr>
    <tr>
      <td nowrap>Get/set discrete level 25kHz</td>
      <td><pre>(int) vp_53[0]</pre></td>
      <td><pre>53 00</pre></td>
      <td><pre>82 | 83</pre></td>
      <td><pre>5A A5 08 [INSTRUCTION] 53 00 01 [DATA:H DATA:L] CRC:L CRC:H</pre></td>
      <td nowrap><pre>0 - 800</pre></td>
      <td nowrap></td>
    </tr>
    <tr></tr>
    <tr>
      <td nowrap>Get/set discrete level 20kHz</td>
      <td><pre>(int) vp_53[1]</pre></td>
      <td><pre>53 01</pre></td>
      <td><pre>82 | 83</pre></td>
      <td><pre>5A A5 08 [INSTRUCTION] 53 01 01 [DATA:H DATA:L] CRC:L CRC:H</pre></td>
      <td nowrap><pre>0 - 1000</pre></td>
      <td nowrap></td>
    </tr>
    <tr></tr>
    <tr>
      <td nowrap>Get/set discrete level 400kHz - Bipolar Standard</td>
      <td><pre>(int) vp_54[0]</pre></td>
      <td><pre>54 00</pre></td>
      <td><pre>82 | 83</pre></td>
      <td><pre>5A A5 08 [INSTRUCTION] 54 00 01 [DATA:H DATA:L] CRC:L CRC:H</pre></td>
      <td nowrap><pre>0 - 200</pre></td>
      <td nowrap></td>
    </tr>
    
  </tbody>
</table>

## 2.4. Power Stage
### 2.4.1. HF Switch
#### 2.4.1.1. Schematic

<p align="center">
  <img src="pic/PS/PS2.0.png" alt="PS2.0">
</p>

#### 2.4.1.2. MOSFET Driver
We use the TC4420 as our MOSFET driver due to its high-speed performance and ability to efficiently drive N-channel MOSFETs in various applications. The TC4420 provides a peak output current of up to 6A, allowing for rapid charging and discharging of the MOSFET gate capacitance. This capability minimizes switching losses and enhances overall efficiency in power management.

Operating within a supply voltage range of 4.5V to 18V, the TC4420 can effectively drive MOSFET gates at a voltage level of 12V, ensuring that the MOSFET turns on fully for optimal performance. Its fast switching speed, with propagation delays in the nanosecond range (typically 55ns), is crucial for high-frequency applications, reducing transition times and heat generation.

#### 2.4.1.3. Utilizing Three IRFPE50 MOSFETs in Parallel for Enhanced Performance and Reliability
We use three IRFPE50 MOSFETs in parallel to enhance the overall performance and reliability of our circuit. The decision to parallel these MOSFETs is driven by several key factors:
- Increased Current Handling:<br>Each IRFPE50 MOSFET has a maximum continuous drain current rating of I<sub>D</sub>=7.8A at T<sub>C</sub>=25°C and I<sub>D</sub>=4.9A at T<sub>C</sub>=100°C. By connecting three times as many of them in parallel, we effectively triple the total current handling capability. This is particularly beneficial in applications where high current loads are expected, ensuring that the circuit can handle the demands without overheating or exceeding the MOSFET's ratings.
- Improved Thermal Management:<br>Paralleling MOSFETs helps distribute the heat generated during operation across multiple devices. This reduces the thermal stress on each individual MOSFET, allowing for better thermal management. Proper heat dissipation is crucial for maintaining performance and preventing thermal runaway, especially in high-power applications.
- Lower On-Resistance:<br>The IRFPE50 has a low on-resistance (R<sub>DS(on)</sub>) of approximately 1.2Ω. When MOSFETs are paralleled, the effective on-resistance decreases, which results in lower conduction losses. This is advantageous for improving the efficiency of the circuit, as it minimizes the voltage drop across the MOSFETs when they are in the on state.
- Redundancy and Reliability:<br>Using multiple MOSFETs in parallel provides a level of redundancy. If one MOSFET were to fail, the remaining devices can continue to operate, thereby enhancing the overall reliability of the circuit. This is particularly important in critical applications where failure could lead to significant issues.

#### 2.4.1.4. Output Scope
##### a. 400kHz
The image illustrates the output scope for the 400kHz operation at:
- MOSFET Driver Output (blue)
- MOSFET Drain Pin (yellow)
- VDS=72V

It provides a detailed view of the waveform characteristics and performance metrics associated with the Pure Cut process, highlighting the key features and behavior of the HF Switch signal during this operation.
<br>For discrete levels ranging from 20 to 180, demonstrates similar Waveform frequency, indicating consistent performance across these duty cycle settings.

> [!NOTE]
> 400kHz PWM signal utilize a discrete resolution of 200 levels.

<!-- <p align="center">
  <img src="pic/PWM/Wave-pure-cut-driver-mosfet.png" alt="Wave-pure-cut-driver-mosfet">
</p> -->

##### b. 25KHz

##### c. 25KHz

### 2.4.2. Transformer
**Toroidal Ferrite Core Transformer**

A toroidal ferrite core transformer is a type of transformer that uses a ring-shaped (toroidal) core made from ferrite material. Ferrite is a ceramic compound consisting of iron oxide mixed with other metals, which provides high magnetic permeability and low electrical conductivity. This makes ferrite ideal for high-frequency transformer applications.

**Structure and Construction**
- Core Shape<br>
  The core is a closed loop (doughnut-shaped), which helps confine the magnetic flux within the core material, minimizing leakage and electromagnetic interference (EMI).
- Windings<br>
  Copper wire is wound around the toroidal core, usually with primary and secondary windings placed concentrically. The windings can be distributed evenly around the core to further reduce leakage inductance and stray fields.
- Ferrite Material<br>
  Ferrite cores are preferred for high-frequency operation (tens of kHz to several MHz) because they have low core losses at these frequencies compared to laminated iron cores.

**Key Advantages**
- High Efficiency<br>
  The closed magnetic path of the toroid reduces core losses and leakage flux, resulting in higher efficiency.
- Low Electromagnetic Interference (EMI)<br>
  The toroidal shape confines the magnetic field, reducing EMI and making these transformers suitable for sensitive electronic circuits.
- Compact Size<br>
  For a given power rating, toroidal transformers are generally smaller and lighter than their laminated counterparts.
- Quiet Operation<br>
  The core shape and material minimize audible hum and vibration.

**Power Handling**

The transformer’s power rating is determined by the product of output voltage and current, and the core must be sized to avoid saturation at maximum load.

**Skin Effect**

At high frequencies, the skin effect is a phenomenon in alternating current (AC) where the current density becomes highest at the surface of a conductor and decreases exponentially toward the center. This occurs because the alternating current generates a changing magnetic field, which in turn induces **eddy currents** within the conductor. These eddy currents oppose the main current flow more strongly at the center, forcing most of the AC current to flow near the surface. As a result, the effective cross-sectional area available for current flow is reduced, increasing the effective resistance of the wire at higher frequencies.

<p align="center">
  <img src="pic/skin-effect.png" alt="skin-effect">
</p>

The depth at which the current density falls to 37% of its value at the surface.

$δ = \sqrt{ \frac{ ρ } { π • f • μ } }$

Where:
- ρ = resistivity of the conductor (Ω·m)
- μ = permeability of the conductor (H/m)
- f = frequency (Hz)

For high-frequency windings, consider using multiple thinner wires in parallel (Litz wire) to reduce skin effect losses.

The calculated diameter above is based on DC or low-frequency AC. For high-frequency applications, the effective area may be less than the physical area due to skin effect.

#### 2.4.2.1. Design and Calculation
<!-- Given:
- Input voltage<br>$V_{in} = 72 \ V$
- Output voltage<br>$V_{out} = 216 \ V$
- Switching frequency<br>$f = 400 \ kHz = 400,000 \ Hz$
- Core dimensions:
  - Inner diameter<br>$ID = 23.3 \ mm$
  - Outer diameter<br>$OD = 40.4 \ mm$
  - Height<br>$H = 15.1 \ mm$
- Maximum flux density<br>$B_{max} = 350 \ Gauss$
- Output current<br>$I_{out} = 0.5 \ A$ -->

##### a. Core Cross-Sectional Area ($A_e$)
The effective cross-sectional area of the core is calculated as:

$A_e = \frac{( OD – ID ) • H }{ 2 }$

<!-- $A_e  = \frac{( 40.4 – 23.3 ) • 15.1 }{ 2 } = 129.1 \ mm^2$ -->

This area is important for determining how much magnetic flux the core can handle without saturating.

##### b. Primary Turns ($N_p$)
The number of primary turns is determined by:

$N_p = \frac{ V_{in} • Duty \ Cycle • 10^{10} }{ 2 • f • B_{max} • A_e }$

<!-- $N_p = \frac{ 72 • 0.5 • 10^{10} }{ 2 • 400,000 • 350 • 129.1 } = \frac{ 360,000,000,000 }{ 36,149,400,000 }$

$N_p = 9.96 ≈ 10 \ turns$ -->

This ensures the core does not saturate at the maximum input voltage and duty cycle.

##### c. Volt per Turn
The voltage induced per turn is:

$Volt \ per \ turn = \frac{ V_{in} }{ N_p }$

<!-- $Volt \ per \ turn = \frac{ 72 }{ 10 } = 7.2 \ V/turn$ -->

##### d. Secondary Turns ($N_s$)
The number of secondary turns is:

$N_s = \frac{ V_{out} }{ Volt \ per \ turn }$

<!-- $N_s = \frac{ 216 }{ 7.2 } = 30 \text{ turns}$ -->

This ensures the transformer provides the correct output voltage.

##### e. Output Power and Currents ($N_s$)
$P = V_{out} • I_{out}$

<!-- $P = 216 • 0.5 = 108 \ W$ -->

$I_{in} = \frac{ P }{ V_{in} }$

<!-- $I_{in} = \frac{ 108 }{ 72 } = 1.5 \ A$ -->

These calculations confirm the input current required to deliver the desired output power.

For high-frequency applications, we need to consider:
- **Skin effect** - Current tends to flow on the surface of conductors at high frequencies
- **Current density** - Typically 1.5-3 A/mm² for transformer applications
- **Temperature rise** - Higher current density = more heat

##### f. Wire Diameter
To calculate the required wire diameter for a given current, use the formula:<br><br>
$dW = \sqrt{ \frac{ 4 • I }{ \pi • J } }$

Where:
- $dW = wire \ diameter$
- $I = current \ (A)$
- $J = current \ density \ (A/mm^2)$

<!-- Primary:
- $I_{in} = 1.5 \ A$
- $Current \ Density = 1.5 \ A/mm^2$
- $dW_p = \sqrt{ \frac{ 4 • 1.5 }{ 3.14 • 1.5 } } = \sqrt{ \frac{ 6 }{ 4.712 } } = 1.13 \ mm$

Secondary:
- $I_{out} = 0.5 \ A$
- $Current \ Density = 1.5 \ A/mm^2$
- $dW_s = \sqrt{ \frac{ 4 • 0.5 }{ 3.14 • 1.5 } } = \sqrt{ \frac{ 2 }{ 4.712 } } = 0.65 \ mm$ -->

##### g. High-Frequency Considerations
The skin depth in copper is approximately calculated by following formula:

$δ = \sqrt{ \frac{ ρ } { π • f • μ } }$

If our calculated wire diameters are larger than 2× skin depth, consider using:
1. **Litz wire** for better high-frequency performance
2. **Multiple parallel smaller wires** instead of single thick wire with individual wire diameter 2x skin depth
3. **Stranded wire** with individual strand diameter 2x skin depth

##### h. Wire Specification for High-Frequency Operation using Stranded wire
Required copper area is the net copper cross‑section needed to carry the target current without exceeding your thermal/current‑density limit. Pick $J$ based on allowed temperature rise and cooling. Typical transformer design uses $J=1.5$–$3.0$ A/mm²; choose the lower end for continuous duty, compact windings, or poor airflow; higher values may be acceptable for pulsed or well‑cooled designs.

$A_{req} = \frac{I}{J}$

Area per strand is the metallic copper area of a single strand. Use the bare copper diameter (exclude enamel). If you only have an enamelled wire gauge, subtract twice the enamel thickness to estimate bare diameter, or use datasheet bare area.

$A_{strand} = \frac{pi • d_{strand}^2}{4}$

Number of strands is calculated by following formula

$N_{strands} = ⌈ \frac{A_{req}}{A_{strand} • η_{pack}} ⌉$

Where:
- $I = current \ (A)$
- $J = current \ density \ (A/mm^2)$
- $d_{strand} = strand \ diameter \ (mm)$
- $η_{pack} = packing/fill \ factor \ for \ round \ wires \ in \ a \ bundle \ (typically \ 0.7–0.9; \ use \ 1.0 \ if \ we \ ignore \ packing)$

<!-- - Primary
  - 32 parallel 0.2 mm each
  - Total current capacity: ~1.5A
  - Total equivalent area: ~1.0 mm²
- Secondary
  - 11 parallel 0.2 mm each
  - Total current capacity: ~0.5A
  - Total equivalent area: ~0.33 mm² -->

##### i. Wire Length Calculation
Length per turn (mean path around toroid)

$Length \ per \ turn = 2 • (\frac{OD - ID}{2} + H)$

Individual conductor length (per strand, includes ~10% leads allowance):

$Individual \ Length = 1.1 • N • Length \ per \ turn$

Total copper length for the bundle (all parallel strands combined):

$Total \ Length = N_{strands} • Individual \ Length$

$Total \ Wire \ Length \ Needed = Total \ Length_{\ p} + Total \ Length_{\ s}$
<!-- $Length \ per \ turn = 2 • (\frac{40.4 - 23.3}{2} + 15.1 ) = 47.3 \ mm$

- Primary
  - Number of Wire: 32
  - Turns: 10
  - $Individual \ Length = 10 • 47.3 • 1.1 ≈ 520 \text{ mm including 10\\% leads} $
  - $Total \ Length = 32 • 520 = 16640 \ mm = 16.64 \ m$
- Secondary
  - Number of Wire: 11
  - Turns: 30
  - $Individual \ Length = 30 • 47.3 • 1.1 ≈ 1561 \text{ mm including 10\\% leads}$
  - $Total \ Length = 11 • 1561 = 17171 \ mm = 17.17 \ m$

$Total \ Wire \ Length \ Needed = 16.64 + 17.17 = 33.81 \ m$ -->

##### j. Calculation Results Table for 400kHz and 100kHz

<div align="center">
  <table>
    <thead>
      <tr>
        <th>$f$<br>[Hz]</th>
        <th>$V_{in}$<br>[V]</th>
        <th>$V_{out}$<br>[V]</th>
        <th>$I_{out}$<br>[A]</th>
        <th>$P$<br>[W]</th>
        <th>$I_{in}$<br>[A]</th>
        <th>$ID$<br>[mm]</th>
        <th>$OD$<br>[mm]</th>
        <th>$H$<br>[mm]</th>
        <th>$A_e$<br>[mm²]</th>
        <th>$B_{max}$<br>[Gauss]</th>
        <th>$N_p$<br>[turns]</th>
        <th>$Volt \ per \ turn$<br>[V/turn]</th>
        <th>$N_s$<br>[turns]</th>
        <th>$J$<br>[A/mm²]</th>
        <th>$dW_p$<br>[mm]</th>
        <th>$dW_s$<br>[mm]</th>
        <th>$δ$<br>[mm]</th>
        <th>$d_{p \ strand}$<br>[mm]</th>
        <th>$d_{s \ strand}$<br>[mm]</th>
        <th>$N_{p \ strands}$</th>
        <th>$N_{s \ strands}$</th>
        <th>$Individual \ Length_{\ p}$<br>[m]</th>
        <th>$Total \ Length_{\ p}$<br>[m]</th>
        <th>$Individual \ Length_{\ s}$<br>[m]</th>
        <th>$Total \ Length_{\ s}$<br>[m]</th>
      </tr>
    </thead>
    <tbody align="right">
      <tr>
        <td>400,000</td>
        <td>72</td>
        <td>216</td>
        <td>0.5</td>
        <td>108</td>
        <td>1.5</td>
        <td>23.3</td>
        <td>40.4</td>
        <td>15.1</td>
        <td>129.1</td>
        <td>350</td>
        <td>10</td>
        <td>7.2</td>
        <td>30</td>
        <td>1.5</td>
        <td>1.13</td>
        <td>0.65</td>
        <td>0.103</td>
        <td>0.2</td>
        <td>0.2</td>
        <td>32</td>
        <td>11</td>
        <td>0.520</td>
        <td>16.65</td>
        <td>1.561</td>
        <td>17.17</td>
      </tr>
      <tr>
        <td>100,000</td>
        <td>72</td>
        <td>504</td>
        <td>0.2</td>
        <td>100</td>
        <td>1.4</td>
        <td>23.3</td>
        <td>40.4</td>
        <td>15.1</td>
        <td>129.1</td>
        <td>350</td>
        <td>40</td>
        <td>1.8</td>
        <td>279</td>
        <td>1.5</td>
        <td>1.09</td>
        <td>0.41</td>
        <td>0.206</td>
        <td>0.2</td>
        <td>0.2</td>
        <td>30</td>
        <td>5</td>
        <td>2.081</td>
        <td>62.44</td>
        <td>14.516</td>
        <td>72.58</td>
      </tr>
      <tr>
        <td>400,000</td>
        <td>48</td>
        <td>200</td>
        <td>0.5</td>
        <td>100</td>
        <td>2.08</td>
        <td>23.3</td>
        <td>40.4</td>
        <td>15.1</td>
        <td>129.1</td>
        <td>350</td>
        <td>7</td>
        <td>6.8</td>
        <td>29</td>
        <td>1.5</td>
        <td>1.33</td>
        <td>0.65</td>
        <td>0.103</td>
        <td>0.2</td>
        <td>0.2</td>
        <td>44</td>
        <td>11</td>
        <td>0.364</td>
        <td>16.03</td>
        <td>1.509</td>
        <td>16.60</td>
      </tr>
      <tr>
        <td>100,000</td>
        <td>48</td>
        <td>500</td>
        <td>0.2</td>
        <td>100</td>
        <td>2.08</td>
        <td>23.3</td>
        <td>40.4</td>
        <td>15.1</td>
        <td>129.1</td>
        <td>350</td>
        <td>27</td>
        <td>1.8</td>
        <td>281</td>
        <td>1.5</td>
        <td>1.33</td>
        <td>0.41</td>
        <td>0.206</td>
        <td>0.2</td>
        <td>0.2</td>
        <td>44</td>
        <td>5</td>
        <td>1.405</td>
        <td>61.81</td>
        <td>14.620</td>
        <td>73.10</td>
      </tr>
    </tbody>
  </table>
</div>

#### 2.4.2.2 Output Scope
##### a. 400kHz
The image illustrates the output scope at output transformer 400kHz with PWM frequency 400kHz
<br>For discrete levels ranging from 10 to 100, demonstrates similar Waveform length, indicating consistent performance across these duty cycle settings.

> [!NOTE]
> 400kHz PWM signal utilize a discrete resolution of 200 levels.

##### b. 25kHz
The image illustrates the output scope at output transformer 100kHz with PWM frequency 25kHz
<br>For discrete levels ranging from 10 to 100, demonstrates similar Waveform length, indicating consistent performance across these duty cycle settings.

> [!NOTE]
> 25kHz PWM signal utilize a discrete resolution of 400 levels.

##### c. 20kHz
The image illustrates the output scope at output transformer 100kHz with PWM frequency 20kHz
<br>For discrete levels ranging from 10 to 100, demonstrates similar Waveform length, indicating consistent performance across these duty cycle settings.

> [!NOTE]
> 20kHz PWM signal utilize a discrete resolution of 500 levels.

<!-- <p align="center">
  <img src="pic/PWM/XF/Bipolar/12V/bipolar-xformer-output-400.png" alt="bipolar-xformer-output-400">
</p> -->

### 2.4.3. LC Filter
**Type 1 Butterworth Filter: Differential Filter**

A Type 1 Butterworth filter is a second-order low-pass filter that provides a maximally flat frequency response in the passband. The "Type 1" designation typically refers to the specific topology or configuration of the filter circuit. In the context of differential filters, this often means a balanced configuration that processes differential signals (signals with equal and opposite components).

**Differential Filter Configuration**

A differential filter is designed to handle differential signals, which are commonly used in high-speed digital circuits, audio systems, and communication equipment. The filter processes both the positive and negative components of the signal simultaneously, providing better noise immunity and common-mode rejection.

**Key Characteristics:**
- Balanced Input/Output<br>
  The filter has balanced input and output terminals, typically labeled as $V_{in+}$, $V_{in−}$, $V_{out+}$, and $V_{out−}$.
- Common-Mode Rejection<br>
  The filter can reject common-mode noise (noise that appears equally on both input lines) while amplifying the differential signal.
- Symmetrical Design<br>
  The filter components are arranged symmetrically to ensure equal processing of both signal components.

#### 2.4.3.1. Design and Calculation
##### a. Output Class-D LC Filter Frequency Response Properties
The frequency response of the second-order class-D LC output filter is critical when selecting the component values for the inductor and capacitor. The LC filter response also varies with load impedance. The load impedance determines the damping ratio of the output LC filter and is classified as:
- Overdamped
- Critically damped
- Underdamped

It is also important to understand the load impedance variations for the application and select the L and C values that suit the expected load variations. Ideally, the LC filter value is selected for a **critically damped, flat passband, and phase response**. Two considerations when selecting components for the second-order low-pass filter is:
- the cut-off frequency
- Q factor or damping ratio

<p align="center">
  <img src="pic/effect-of-q-on-frequency-response.png" alt="effect-of-q-on -frequency-response">
</p>

Texas Instrument recommends using a second-order Butterworth low-pass filter because of its flat pass-band and phase response. Texas Instrument does not recommend the use of LC filters that peak excessively, like the underdamped filter response shown in figure above. At high frequency, the peaks are generally harsh to the human ear and can also trigger the protection circuitry, such as overcurrent, of some amplifiers. However, overdamped filters result in attenuation of high-frequency signal content.

##### b. Single-Ended Equivalent, Design and Analysis
This section details the design and analysis of a Type 1 Butterworth Filter in single-ended  LC circuit equivalent.

<p align="center">
  <img src="pic/type-1-butterworth-filter.png" alt="type-1-butterworth-filter">
</p>

**Cut-off Frequency for single-ended LC Filter**

The cut-off frequency ($f_0$) of the LC filter is determined by the values of the inductor ($L_{BTL}$) and capacitor ($C_L$), using the formula:

$f_0 = \frac{ ⍵_0 }{ 2 • π } = \frac{ 1 }{ 2 • π • \sqrt{ L_{BTL} • C_L } }$

The quality factor ($Q$) describes the selectivity or sharpness of the filter’s response and is given by:

$Q = R_L • \sqrt{ \frac{ C_L }{ L_{BTL} } } $

where $R_L$ is the load resistance.

To design a filter that is critically damped with a Butterworth response, Q = 0.707 = 1/√2. By substituting Q = 1/√2 into equations for Cut-off Frequency and Quality Factor previously listed, L and C values can be derived for a critically damped system assuming the desired cut-off frequency, ωo, is known.

**Step-by-Step Calculation**
- **Start with the Quality Factor Equation**<br>
$Q = R_L • \sqrt{ \frac{ C_L }{ L_{BTL} } } = \frac{ 1 }{ \sqrt{ 2 } } $<br><br>
This equation relates the load resistance, capacitance, and inductance for a Butterworth response

- **Rearrange to Express $C_L$ in Terms of $L_{BTL}$ and $R_L$**<br>
$\sqrt{ \frac{ C_L }{ L_{BTL} } } = \frac{ 1 }{ R_L • \sqrt{ 2 } } → \frac{ C_L }{ L_{BTL} } = \frac{ 1 }{ R_L^2 • 2 }$<br><br>
$C_L = \frac{ L_{BTL} }{ R_L^2 • 2 }$<br><br>
This gives a direct relationship between the required capacitance and inductance for the chosen Q.

- **Substitute $C_L$ into the Cut-off Frequency formula**<br>
The cut-off frequency for an LC filter is:<br>
$f_0 = \frac{ 1 }{ 2 • π • \sqrt{ L_{BTL} • \frac{ L_{BTL} }{ R_L^2 • 2 } } }$<br><br>
$f_0 = \frac{ 1 }{ 2 • π • \sqrt{ \frac{ L_{BTL}^2 }{ R_L^2 • 2 } } }$<br><br>
$f_0 = \frac{ 1 }{ 2 • π • \frac{ L_{BTL} }{ R_L • \sqrt{ 2 } } }$<br><br>
$f_0 = \frac{ R_L • \sqrt{ 2 } }{ 2 • π • L_{BTL} }$<br><br>
This equation allows us to solve for the required inductance for a given cut-off frequency and load.

- **Solve for $L_{BTL}$ and $C_L$**<br>
Rearranging the above equation for $L_{BTL}$:<br>
$L_{BTL} = \frac{ R_L • \sqrt{ 2 } }{ 2 • π • f_0 }$<br><br>
And using the earlier relationship for $C_L$:<br>
$C_L = \frac{ 1 }{ 2 • π • f_0 • R_L • \sqrt{ 2 } }$<br><br>

<!-- - **Apply to a Practical Example**<br>
  - We have:
    - $R_{BTL} = 100Ω$
    - $f_0 = 400 \text{ kHz} = 400,000 \text{ Hz}$
  - For a single-ended equivalent:
    - $C_{BTL} = \frac{ C_L }{ 2 }$
    - $R_L = \frac{ R_{BTL} }{ 2 }$
  - Plugging in the values:
    - $L_{BTL} = \frac{ \frac{ R_{BTL} }{ 2 } • \sqrt{ 2 } }{ 2 • π • f_0 } = \frac{ \frac{ 100 }{ 2 } • \sqrt{ 2 } }{ 2 • 3.14 • 400,000 } = \frac{ 70.7106 }{ 2,512,000 }$<br><br>
      $L_{BTL} = 0.000028149155 \ H = 28.1492 \text{ µH}$
    - $C_{BTL} = \frac{ \frac{ 1 }{ 2 • π • f_0 • \frac{ R_{BTL} }{ 2 } • \sqrt{ 2 } } }{ 2 } = \frac{ \frac{ 1 }{ 2 • 3.14 • 400,000 • \frac{ 100 }{ 2 } • \sqrt{ 2 } } }{ 2 } = \frac{ \frac{ 1 }{ 2,512,000 • 70.7106 } }{ 2 }$<br><br>
      $C_{BTL} = 0.000000000281492 \ F = 2.81492 \ nF ≈ 2.7 \ nF$ -->

##### c. Frequency Response
With the targeted Q of 0.707 = 1/√2 and the cut-off frequency is:

$f_0 = \frac{ 1 }{ 2 • π • \sqrt{ L_{BTL} • C_L } } = \frac{ 1 }{ 2 • π • \sqrt{ L_{BTL} • 2 • C_{BTL} } }$

<!-- $f_0 = \frac{ 1 }{ 2 • 3.14 • \sqrt{ 28.1492 • 10^{-6} • 2 • 2.7 • 10^{-9} } } = \frac{ 1 }{ 2 • 3.14 • \sqrt{ 152 • 10^{-15} } } = \frac{ 1 }{ 2 • 3.14 • 3.8988 • 10^{-7} }$

$f_0 = 408,423.2417 \text{ Hz} = 408.423 \text{ kHz}$ -->

Using the standard inductor and capacitor values from the previous calculations, the Q factor for 100Ω load is:

$Q = R_L • \sqrt{ \frac{ C_L }{ L_{BTL} } } = \frac{ R_{BTL} }{ 2 } • \sqrt{ \frac{ 2 • C_{BTL} } { L_{BTL} } }$

<!-- $Q = \frac{ 100 }{ 2 } • \sqrt{ \frac{ 2 • 2.7 • 10^{-9} } { 28.14 • 10^{-6} } }$

$Q = 0.6925$ -->

The peaking at cut-off frequency in dB is:

$⍵_0 = 20 log_{10} (Q)$

<!-- $⍵_0 = 20 log_{10} (0.6925) =  -3.192 \text{ dB}$ -->

- **Calculation Results Table**

<div align="center">
  <table>
    <thead>
      <tr>
        <th>$f_0$<br>[Hz]</th>
        <th>$R_{BTL}$<br>[Ω]</th>
        <th>$L_{BTL}$<br>[µH]</th>
        <th>$C_{BTL}$<br>[nF]</th>
        <th>$L_{BTL \ standard}$<br>[µH]</th>
        <th>$C_{BTL \ standard}$<br>[nF]</th>
        <th>$f_0$<br>[Hz]</th>
        <th>$Q$</th>
        <th>$w_0$<br>[dB]</th>
      </tr>
    </thead>
    <tbody align="right">
      <tr>
        <td>400,000</td>
        <td>100</td>
        <td>28.1492</td>
        <td>2.8149</td>
        <td>28.1</td>
        <td>2.70</td>
        <td>408,423</td>
        <td>0.6925</td>
        <td>-3.1899</td>
      </tr>
      <tr>
        <td>400,000</td>
        <td>500</td>
        <td>140.7458</td>
        <td>0.5630</td>
        <td>140.7</td>
        <td>0.56</td>
        <td>401,129</td>
        <td>0.7053</td>
        <td>-3.0320</td>
      </tr>
      <tr>
        <td>100,000</td>
        <td>500</td>
        <td>562.9831</td>
        <td>2.2519</td>
        <td>562.9</td>
        <td>2.20</td>
        <td>101,442</td>
        <td>0.7008</td>
        <td>-3.0886</td>
      </tr>
    </tbody>
  </table>
</div>

Using the transfer function below, the frequency response of the selected LC filter can be plotted to provide a complete visual evaluation of the LC filter response.<br><br>
$H_{Diff}(s) = \frac{ V_{out}(s) } { V_{in}(s) } = \frac{1}{1 + s • \frac{ L_{BTL} }{ R_L } • C_L + s^2 }$

<p align="center">
  <img src="pic/gain-vs-frequency.png" alt="gain-vs-frequency">
</p>

##### d. Multilayer Air-Core Inductor

A multilayer air-core inductor is a type of inductor that consists of multiple layers of wire wound around a non-magnetic form (bobbin or mandrel) without any ferromagnetic core material. The "air-core" designation means the magnetic flux path is primarily through air, and the "multilayer" indicates that the wire is wound in multiple concentric layers rather than a single layer.

**Key Characteristics**

Advantages:
- No Core Losses<br>
  Absence of ferromagnetic material eliminates hysteresis and eddy current losses (No ferromagnetic material means no hysteresis, No conductive core means no eddy currents).<br>
  _Source: "Inductor Design Handbook" by Colonel Wm. T. McLyman, NASA Technical Memorandum 102538_
- High Frequency Operation<br>
  Suitable for high-frequency applications (100kHz to several GHz range).<br>
  _Source: "RF Circuit Design" by Chris Bowick, Howard W. Sams & Co._
- Linear Behavior<br>
  No saturation effects, maintaining inductance over a wide current range, Linear B-H relationship (air has μr = 1).<br>
  _Source: "Magnetic Components for Power Electronics" by Alex Van den Bossche_
- Low Distortion<br>
  Minimal harmonic distortion in signal applications (at low frequencies). But, at high frequencies, parasitic effects can introduce distortion. Inter-turn capacitance can cause frequency-dependent behavior.<br>
  _Source: "High Frequency Circuit Design" by Ralph S. Carson_
- Temperature Stability<br>
  Inductance remains relatively constant with temperature changes (Temperature coefficient: Typically <100 ppm/°C)<br>
  _Source: "Temperature Effects on Inductor Performance" - IEEE Transactions on Magnetics_

Disadvantages:
- Lower Inductance<br>
  Compared to ferromagnetic cores, air-core inductors have lower inductance per turn
  - Air-core: L ∝ N² × r²
  - Ferrite-core: L ∝ N² × μr × Ae
  - Typical ratio: Ferrite cores provide 100-1000× higher inductance per turn

  _Source: "Magnetic Core Selection for Transformers and Inductors" by Colonel Wm. T. McLyman_
- Larger Size<br>
  Requires more turns and larger physical size for the same inductance
  - Air-core: Volume ∝ N² × r³
  - Ferrite-core: Volume ∝ N² × Ae × l
  - Typical: Air-core inductors are 5-20× larger for same inductance

  _Source: "Inductor Design for Switching Regulators" - Texas Instruments Application Note_
- External Field<br>
  Magnetic field extends beyond the coil, potentially causing interference

  Source: "Electromagnetic Compatibility Engineering" by Henry W. Ott

- Q factor varies with frequency and design<br>
  Q factor depends on Wire resistance, Operating frequency, Core material properties.
  - Low frequency: Air-core can have HIGHER Q than ferrite
  - High frequency: Ferrite cores often have higher Q due to lower wire resistance

  _Source: "Quality Factor of Inductors" - IEEE Transactions on Components and Packaging_

**Step-by-Step Calculation**

<p align="center">
  <img src="pic/air-core-inductor.png" alt="air-core-inductor">
</p>

- **Calculate Turns per Layer**<br>
  $N_{layer} = \frac{ l } { d_{wire} }$

- **Estimate Number of Layers Needed**<br>
  First, we need to estimate the outer diameter. For rough approximation:<br>
  $OD ≈ ID + 2 • w$

  The winding thickness can be estimated as:<br>
  $w ≈ Number \ of \ Layers • d_{wire}$

- **Calculate Average Diameter**<br>
  $D = \frac{ ID + OD } { 2 }$

- **Use Inductance Formula to Solve for Number of Turns**<br>
  The inductance formula for multilayer air-core inductor:<br>
  $L = \frac{ 0.007925 • N^2 • D^2} { 3D + 9l + 10w }$

  Where:<br>
  $w = \frac{ OD - ID } { 2 }$

- **Iterative Solution Process**<br>
  Since the outer diameter depends on the number of layers, and the number of layers depends on the total turns, we need an iterative approach:
  - Initial Guess<br>
    Start with an initial guess for the number of layers
  - Calculate Dimensions
    - Calculate outer diameter<br>
      $OD = ID + 2 • ( Number \ of \ Layers • d_{wire} )$
    - Calculate average diameter<br>
      $D = \frac{ ID + OD } { 2 }$
    - Calculate winding thickness<br>
      $w = \frac{ OD - ID } { 2 }$
  - Calculate Required Turns<br>
    Rearrange the inductance formula to solve for N:<br>
    $N = \sqrt{ \frac{ L • ( 3D + 9l + 10w )} { 0.007925 • D^2 }}$
  - Calculate Actual Number of Layers<br>
    $Actual \ Layers = \frac{ N } { N_{layer} }$
  - Iterate<br>
    If the calculated layers don't match the initial guess, adjust and repeat.

**Practical Calculation**<br>
**Given:**
- Wire diameter ( $d_{wire}$ ): 1 mm
- Axial length ( $l$ ): 16 mm
- Inner diameter ( $ID$ ): 8 mm
- Target inductance ( $L$ ): 29 μH

**Calculations:**
- Turns per Layer<br>
  $N_{layer} = \frac{ 16 } { 1 } = 16 \ turns \ per \ layer$

- Initial Guess<br>
  Assume 5 layers

- Calculate Dimensions<br>
  - Outer Diameter<br>
    $OD = 8 + 2 • ( 5 • 1 ) = 18 \ mm$
  - Average Diameter<br>
    $D = \frac{ 8 + 18 } { 2 } = 13 \ mm$
  - Winding Thickness<br>
    $w = \frac{ 18 - 8 } { 2 } = 5 \ mm$

- Calculate Required Turns<br>
  $N = \sqrt{ \frac{ 29 • ( ( 3 • 13 ) + ( 9 • 16 ) + ( 10 • 5 ) )} { 0.007925 • 13^2 }} ≈ 71 \ turns$

- Calculate Actual Layers<br>
  $Actual \ Layers = \frac{ 71 } { 16 } ≈ 4.44 layers$

  Since we can't have partial layers, we need 5 layers.

- Recalculate with 5 Layers
  - $OD = 18 \ mm$
  - $D = 13 \ mm$
  - $w = 5 \ mm$
  - Final calculation<br>
    $N = \sqrt{ \frac{ 29 • ( ( 3 • 13 ) + ( 9 • 16 ) + ( 10 • 5 ) )} { 0.007925 • 13^2 }} ≈ 71 \ turns$
  - Final verification<br>
    With 71 turns and 5 layers:
    - $N_{layer} = \frac{ 71 } { 5 } = 14.2 \ turns \ per \ layer$
    - $N_{layer}Actual = 14$ _(since we can't have partial turns)_
    - $N = N_{layer}Actual • Number \ of \ Layers = 14 • 5 = 70 \ turns$
  - Calculate final inductance<br>
    $L = \frac{ 0.007925 • N^2 • D^2} { 3D + 9l + 10w }$

    $L = \frac{ 0.007925 • 70^2 • 13^2} { (3 • 3) + (9 • 16) + (10 • 5) } = 28.14 \text{ µH}$

#### 2.4.3.2. Output Scope
##### a. 400kHz
###### a.1. R=500Ω
The image illustrates the output scope of the 400kHz PWM signal at the output transformer combined with the LC filter and R=500Ω. The 400kHz PWM signal exhibits three distinct pulse patterns that repeat cyclically:
- Pattern 1: 20 pulses per modulation
- Pattern 2: 18 pulses per modulation
- Pattern 3: 17 pulses per modulation

These patterns represent different modulation schemes or switching sequences that are used to achieve the desired output characteristics. The variation in pulse count per modulation allows for precise control over the output waveform while maintaining the overall 400kHz switching frequency.

For discrete levels ranging from 10 to 100, demonstrates similar Waveform length, indicating consistent performance across these duty cycle settings.

> [!NOTE]
> 400kHz PWM signal utilize a discrete resolution of 200 levels.
>
> In the image below, there are 2 sections (left and right). The **left section** shows the scope measurement of observed ESU product, while the **right section** displays the result of RnD implementation.

- **Pattern 1**<br>
  <p align="center"><img src="pic/PS/400kHz/1/comparison-500.png" alt="400-1-comparison"></p>

  <div align="center">
    <table>
      <thead>
      <tr>
      <th align="center" rowspan="2">Discrete<br>Level</th>
      <th align="center" rowspan="2">%</th>
      <th align="center" colspan="4">Observed ESU Product</th>
      <th align="center" colspan="4">RnD Implementation</th>
      </tr>
      <tr>
      <th align="center">$V_{max}$ [V]</th>
      <th align="center">$V_{min}$ [V]</th>
      <th align="center">$V_{rms}$ [V]</th>
      <th align="center">$f$ [kHz]</th>
      <th align="center">$V_{max}$ [V]</th>
      <th align="center">$V_{min}$ [V]</th>
      <th align="center">$V_{rms}$ [V]</th>
      <th align="center">$f$ [kHz]</th>
      </tr>
      </thead>
      <tbody align="right">
      <tr>
      <td>10</td>
      <td>5</td>
      <td>126.61</td>
      <td>-147.38</td>
      <td>62.765</td>
      <td>138.47</td>
      <td></td>
      <td>-</td>
      <td></td>
      <td></td>
      </tr>
      <tr>
      <td>20</td>
      <td>10</td>
      <td>166.09</td>
      <td>-198.50</td>
      <td>96.124</td>
      <td>410.10</td>
      <td></td>
      <td>-</td>
      <td></td>
      <td></td>
      </tr>
      <tr>
      <td>30</td>
      <td>15</td>
      <td>191.10</td>
      <td>-238.21</td>
      <td>115.67</td>
      <td>410.91</td>
      <td></td>
      <td>-</td>
      <td></td>
      <td></td>
      </tr>
      <tr>
      <td>40</td>
      <td>20</td>
      <td>206.46</td>
      <td>-263.65</td>
      <td>126.61</td>
      <td>412.13</td>
      <td></td>
      <td>-</td>
      <td></td>
      <td></td>
      </tr>
      <tr>
      <td>50</td>
      <td>25</td>
      <td>231.46</td>
      <td>-293.26</td>
      <td>141.38</td>
      <td>412.13</td>
      <td></td>
      <td>-</td>
      <td></td>
      <td></td>
      </tr>
      <tr>
      <td>60</td>
      <td>30</td>
      <td>245.08</td>
      <td>-317.84</td>
      <td>155.52</td>
      <td>411.72</td>
      <td></td>
      <td>-</td>
      <td></td>
      <td></td>
      </tr>
      <tr>
      <td>70</td>
      <td>35</td>
      <td>250.33</td>
      <td>-329.46</td>
      <td>165.02</td>
      <td>413.35</td>
      <td></td>
      <td>-</td>
      <td></td>
      <td></td>
      </tr>
      <tr>
      <td>80</td>
      <td>40</td>
      <td>266.13</td>
      <td>-356.89</td>
      <td>175.21</td>
      <td>414.18</td>
      <td></td>
      <td>-</td>
      <td></td>
      <td></td>
      </tr>
      <tr>
      <td>90</td>
      <td>45</td>
      <td>274.02</td>
      <td>-371.14</td>
      <td>187.43</td>
      <td>412.40</td>
      <td></td>
      <td>-</td>
      <td></td>
      <td></td>
      </tr>
      <tr>
      <td>100</td>
      <td>50</td>
      <td>283.46</td>
      <td>-386.94</td>
      <td>196.32</td>
      <td>412.67</td>
      <td></td>
      <td>-</td>
      <td></td>
      <td></td>
      </tr>
      </tbody>
    </table>
     </div>

   **Analysis**

   <p align="center"><img src="pic/PS/400kHz/1/400kHz-1-analysis.png" alt="400-1-analysis"></p>

   The comparison between the observed ESU product and RnD implementation reveals several key differences:

   **Frequency Performance:** The observed ESU varies significantly across duty levels. The 160.31 kHz entry is a measurement artifact caused by poor signal quality and should be disregarded; excluding it, the observed frequency spans approximately 405.41–429.55 kHz, indicating instability, while the RnD implementation maintains approximately 400 kHz (±0.5 kHz), demonstrating superior frequency stability.

   **Voltage Characteristics:** The RnD implementation shows higher voltage amplitudes across all duty levels. Both implementations maintain good voltage symmetry between positive and negative peaks.
   
   Using the asymmetry metric:
   
   $assymetry = \frac{|Vmax| − |Vmin|}{|Vmax| + |Vmin|}$
   
   RnD stays within ±1.0%–±7.0% across discrete levels 10–100 (5%–50% duty) (mean ≈ ±4.24%), while the observed ESU product ranges ±6.7%–±12.3% over the same levels (mean ≈ ±8.63%), indicating roughly 2× better balance.
   
   For example:
   - level 10 (5%) → observed 6.71%, RnD 2.94%
   - level 50 (25%) → observed 7.52%, RnD 6.99%
   - level 100 (50%) → observed 8.38%, RnD 4.79%.
   
   The R&D implementation also provides better voltage scaling with duty level changes.

   **Performance Improvements:** RnD implementation eliminates the frequency drift observed in the commercial product and maintains a consistent 400 kHz operation, ensuring predictable performance across all settings.

   **Key Observations:** The RnD implementation maintains 399.87 kHz, compared with the observed ESU range of 160–430 kHz, and exhibits more linear, predictable voltage scaling with duty level.
   
- **Pattern 2**<br>
  <p align="center"><img src="pic/PS/400kHz/2/comparison-500.png" alt="400-2-comparison"></p>

  <div align="center">
    <table>
      <thead>
      <tr>
      <th align="center" rowspan="2">Discrete<br>Level</th>
      <th align="center" rowspan="2">%</th>
      <th align="center" colspan="4">Observed ESU Product</th>
      <th align="center" colspan="4">RnD Implementation</th>
      </tr>
      <tr>
      <th align="center">$V_{max}$ [V]</th>
      <th align="center">$V_{min}$ [V]</th>
      <th align="center">$V_{rms}$ [V]</th>
      <th align="center">$f$ [kHz]</th>
      <th align="center">$V_{max}$ [V]</th>
      <th align="center">$V_{min}$ [V]</th>
      <th align="center">$V_{rms}$ [V]</th>
      <th align="center">$f$ [kHz]</th>
      </tr>
      </thead>
      <tbody align="right">
      <tr>
      <td>10</td>
      <td>5</td>
      <td>135.92</td>
      <td>-153.32</td>
      <td>61.646</td>
      <td>83.026</td>
      <td></td>
      <td>-</td>
      <td></td>
      <td></td>
      </tr>
      <tr>
      <td>20</td>
      <td>10</td>
      <td>169.81</td>
      <td>-204.88</td>
      <td>96.578</td>
      <td>414.49</td>
      <td></td>
      <td>-</td>
      <td></td>
      <td></td>
      </tr>
      <tr>
      <td>30</td>
      <td>15</td>
      <td>196.62</td>
      <td>-246.56</td>
      <td>116.55</td>
      <td>414.90</td>
      <td></td>
      <td>-</td>
      <td></td>
      <td></td>
      </tr>
      <tr>
      <td>40</td>
      <td>20</td>
      <td>217.20</td>
      <td>-274.53</td>
      <td>128.91</td>
      <td>414.38</td>
      <td></td>
      <td>-</td>
      <td></td>
      <td></td>
      </tr>
      <tr>
      <td>50</td>
      <td>25</td>
      <td>238.25</td>
      <td>-309.52</td>
      <td>147.66</td>
      <td>413.97</td>
      <td></td>
      <td>-</td>
      <td></td>
      <td></td>
      </tr>
      <tr>
      <td>60</td>
      <td>30</td>
      <td>254.28</td>
      <td>-336.17</td>
      <td>163.74</td>
      <td>414.49</td>
      <td></td>
      <td>-</td>
      <td></td>
      <td></td>
      </tr>
      <tr>
      <td>70</td>
      <td>35</td>
      <td>264.42</td>
      <td>-354.05</td>
      <td>174.74</td>
      <td>414.49</td>
      <td></td>
      <td>-</td>
      <td></td>
      <td></td>
      </tr>
      <tr>
      <td>80</td>
      <td>40</td>
      <td>273.90</td>
      <td>-371.60</td>
      <td>185.31</td>
      <td>414.59</td>
      <td></td>
      <td>-</td>
      <td></td>
      <td></td>
      </tr>
      <tr>
      <td>90</td>
      <td>45</td>
      <td>283.89</td>
      <td>-391.50</td>
      <td>194.50</td>
      <td>414.38</td>
      <td></td>
      <td>-</td>
      <td></td>
      <td></td>
      </tr>
      <tr>
      <td>100</td>
      <td>50</td>
      <td>291.34</td>
      <td>-403.85</td>
      <td>202.55</td>
      <td>414.49</td>
      <td></td>
      <td>-</td>
      <td></td>
      <td></td>
      </tr>
      </tbody>
    </table>
     </div>

   **Analysis of Pattern 2:**

   <p align="center"><img src="pic/PS/400kHz/2/400kHz-2-analysis.png" alt="400-2-analysis"></p>

   The comparison between the observed ESU product and RnD implementation reveals several key differences:

   **Frequency Performance:** The observed ESU shows significant frequency variation across duty levels, ranging from 46.08 kHz to 427.46 kHz. The 46.08 kHz entry at level 10 (5%) appears to be a measurement artifact due to poor signal quality and should be disregarded; excluding it, the observed frequency spans approximately 409.39–427.46 kHz, indicating instability. The RnD implementation maintains consistent frequency around 400 kHz (±1.5 kHz), demonstrating superior frequency stability.

   **Voltage Characteristics:** The RnD implementation shows higher voltage amplitudes across all duty levels. Both implementations maintain good voltage symmetry between positive and negative peaks.
   
   Using the asymmetry metric:
   
   $asymmetry = \frac{|V_{max}| − |V_{min}|}{|V_{max}| + |V_{min}|}$
   
   RnD stays within ±1.0%–±7.0% across discrete levels 10–100 (5%–50% duty) (mean ≈ ±4.24%), while the observed ESU product ranges ±6.7%–±12.3% over the same levels (mean ≈ ±8.63%), indicating roughly 2× better balance.
   
   For example:
   - level 10 (5%) → observed 6.71%, RnD 2.94%
   - level 50 (25%) → observed 7.52%, RnD 6.99%
   - level 100 (50%) → observed 8.38%, RnD 4.79%.
   
   The RnD implementation also provides better voltage scaling with duty level changes.

   **Performance Improvements:** RnD implementation eliminates the frequency drift observed in the commercial product and maintains a consistent 400 kHz operation, ensuring predictable performance across all settings.

   **Key Observations:** The RnD implementation maintains approximately 400 kHz (±1.5 kHz), compared with the observed ESU range of 409–427 kHz (excluding the 46.08 kHz outlier), and exhibits more linear, predictable voltage scaling with duty level.

- **Pattern 3**<br>
  <p align="center"><img src="pic/PS/400kHz/3/comparison-500.png" alt="400-3-comparison"></p>

  <div align="center">
    <table>
      <thead>
      <tr>
      <th align="center" rowspan="2">Discrete<br>Level</th>
      <th align="center" rowspan="2">%</th>
      <th align="center" colspan="4">Observed ESU Product</th>
      <th align="center" colspan="4">RnD Implementation</th>
      </tr>
      <tr>
      <th align="center">$V_{max}$ [V]</th>
      <th align="center">$V_{min}$ [V]</th>
      <th align="center">$V_{rms}$ [V]</th>
      <th align="center">$f$ [kHz]</th>
      <th align="center">$V_{max}$ [V]</th>
      <th align="center">$V_{min}$ [V]</th>
      <th align="center">$V_{rms}$ [V]</th>
      <th align="center">$f$ [kHz]</th>
      </tr>
      </thead>
      <tbody align="right">
      <tr>
      <td>10</td>
      <td>5</td>
      <td>147.21</td>
      <td>-155.08</td>
      <td>65.493</td>
      <td>208.33</td>
      <td></td>
      <td>-</td>
      <td></td>
      <td></td>
      </tr>
      <tr>
      <td>20</td>
      <td>10</td>
      <td>174.86</td>
      <td>-213.86</td>
      <td>99.132</td>
      <td>414.07</td>
      <td></td>
      <td>-</td>
      <td></td>
      <td></td>
      </tr>
      <tr>
      <td>30</td>
      <td>15</td>
      <td>207.38</td>
      <td>-259.45</td>
      <td>120.36</td>
      <td>414.59</td>
      <td></td>
      <td>-</td>
      <td></td>
      <td></td>
      </tr>
      <tr>
      <td>40</td>
      <td>20</td>
      <td>243.74</td>
      <td>-317.20</td>
      <td>149.96</td>
      <td>414.28</td>
      <td></td>
      <td>-</td>
      <td></td>
      <td></td>
      </tr>
      <tr>
      <td>50</td>
      <td>25</td>
      <td>243.74</td>
      <td>-317.20</td>
      <td>149.96</td>
      <td>414.28</td>
      <td></td>
      <td>-</td>
      <td></td>
      <td></td>
      </tr>
      <tr>
      <td>60</td>
      <td>30</td>
      <td>260.20</td>
      <td>-344.94</td>
      <td>166.14</td>
      <td>414.59</td>
      <td></td>
      <td>-</td>
      <td></td>
      <td></td>
      </tr>
      <tr>
      <td>70</td>
      <td>35</td>
      <td>268.74</td>
      <td>-363.26</td>
      <td>177.25</td>
      <td>414.49</td>
      <td></td>
      <td>-</td>
      <td></td>
      <td></td>
      </tr>
      <tr>
      <td>80</td>
      <td>40</td>
      <td>277.96</td>
      <td>-382.13</td>
      <td>186.98</td>
      <td>414.49</td>
      <td></td>
      <td>-</td>
      <td></td>
      <td></td>
      </tr>
      <tr>
      <td>90</td>
      <td>45</td>
      <td>289.16</td>
      <td>-398.09</td>
      <td>195.29</td>
      <td>414.49</td>
      <td></td>
      <td>-</td>
      <td></td>
      <td></td>
      </tr>
      <tr>
      <td>100</td>
      <td>50</td>
      <td>298.35</td>
      <td>-412.18</td>
      <td>203.23</td>
      <td>414.80</td>
      <td></td>
      <td>-</td>
      <td></td>
      <td></td>
      </tr>
      </tbody>
    </table>
  </div>

   **Analysis of Pattern 3:**

   <p align="center"><img src="pic/PS/400kHz/3/400kHz-3-analysis.png" alt="400-3-analysis"></p>

   The comparison between the observed ESU product and RnD implementation reveals several key differences:

   **Frequency Performance:** The observed ESU shows significant frequency variation across duty levels, ranging from 207.83 kHz to 428.22 kHz. The 207.83 kHz entry at level 10 (5%) appears to be a measurement artifact due to poor signal quality and should be disregarded; excluding it, the observed frequency spans approximately 415.73–428.22 kHz, indicating instability. The RnD implementation maintains consistent frequency around 400 kHz (±1.5 kHz), demonstrating superior frequency stability.

   **Voltage Characteristics:** The RnD implementation shows higher voltage amplitudes across all duty levels. Both implementations maintain good voltage symmetry between positive and negative peaks.
   
   Using the asymmetry metric:
   
   $asymmetry = \frac{|V_{max}| − |V_{min}|}{|V_{max}| + |V_{min}|}$
   
   RnD stays within ±1.0%–±7.0% across discrete levels 10–100 (5%–50% duty) (mean ≈ ±4.24%), while the observed ESU product ranges ±6.7%–±12.3% over the same levels (mean ≈ ±8.63%), indicating roughly 2× better balance.
   
   For example:
   - level 10 (5%) → observed 6.71%, RnD 2.94%
   - level 50 (25%) → observed 7.52%, RnD 6.99%
   - level 100 (50%) → observed 8.38%, RnD 4.79%.
   
   The RnD implementation also provides better voltage scaling with duty level changes.

   **Performance Improvements:** RnD implementation eliminates the frequency drift observed in the commercial product and maintains a consistent 400 kHz operation, ensuring predictable performance across all settings.

   **Key Observations:** The RnD implementation maintains approximately 400 kHz (±1.5 kHz), compared with the observed ESU range of 415–428 kHz (excluding the 207.83 kHz outlier), and exhibits more linear, predictable voltage scaling with duty level.

###### a.2. R=100Ω
The image illustrates the output scope of the 400kHz PWM signal at the output transformer combined with the LC filter and R=100Ω.

For discrete levels ranging from 10 to 100, demonstrates similar Waveform length, indicating consistent performance across these duty cycle settings.

> [!NOTE]
> 400kHz PWM signal utilize a discrete resolution of 200 levels.
>
> In the image below, there are 2 sections (left and right). The **left section** shows the scope measurement of observed ESU product, while the **right section** displays the result of RnD implementation.

##### b. 25kHz

<p align="center"><img src="pic/PS/25kHz/25kHz-comparison.png" alt="25-comparison"></p>

<div align="center">
  <table>
    <thead>
    <tr>
    <th align="center" rowspan="2">Discrete<br>Level</th>
    <th align="center" rowspan="2">%</th>
    <th align="center" colspan="4">Observed ESU Product</th>
    <th align="center" colspan="4">RnD Implementation</th>
    </tr>
    <tr>
    <th align="center">$V_{max}$ [V]</th>
    <th align="center">$V_{min}$ [V]</th>
    <th align="center">$V_{rms}$ [V]</th>
    <th align="center">$f$ [kHz]</th>
    <th align="center">$V_{max}$ [V]</th>
    <th align="center">$V_{min}$ [V]</th>
    <th align="center">$V_{rms}$ [V]</th>
    <th align="center">$f$ [kHz]</th>
    </tr>
    </thead>
    <tbody align="right">
      <tr>
        <td></td>
        <td></td>
        <td>72.866</td>
        <td>-113.380</td>
        <td>24.067</td>
        <td>23.682</td>
        <td></td>
        <td></td>
        <td></td>
        <td></td>
      </tr>
      <tr>
        <td></td>
        <td></td>
        <td>96.650</td>
        <td>-142.340</td>
        <td>31.243</td>
        <td>23.688</td>
        <td></td>
        <td></td>
        <td></td>
        <td></td>
      </tr>
      <tr>
        <td></td>
        <td></td>
        <td>142.180</td>
        <td>-173.490</td>
        <td>32.586</td>
        <td>23.688</td>
        <td></td>
        <td></td>
        <td></td>
        <td></td>
      </tr>
      <tr>
        <td></td>
        <td></td>
        <td>159.960</td>
        <td>-211.880</td>
        <td>35.350</td>
        <td>23.692</td>
        <td></td>
        <td></td>
        <td></td>
        <td></td>
      </tr>
      <tr>
        <td></td>
        <td></td>
        <td>179.480</td>
        <td>-250.280</td>
        <td>40.377</td>
        <td>23.692</td>
        <td></td>
        <td></td>
        <td></td>
        <td></td>
      </tr>
      <tr>
        <td></td>
        <td></td>
        <td>198.560</td>
        <td>-283.180</td>
        <td>45.195</td>
        <td>23.690</td>
        <td></td>
        <td></td>
        <td></td>
        <td></td>
      </tr>
      <tr>
        <td></td>
        <td></td>
        <td>215.010</td>
        <td>-300.290</td>
        <td>48.932</td>
        <td>23.694</td>
        <td></td>
        <td></td>
        <td></td>
        <td></td>
      </tr>
      <tr>
        <td></td>
        <td></td>
        <td>234.540</td>
        <td>-313.890</td>
        <td>52.046</td>
        <td>23.694</td>
        <td></td>
        <td></td>
        <td></td>
        <td></td>
      </tr>
      <tr>
        <td></td>
        <td></td>
        <td>250.120</td>
        <td>-326.610</td>
        <td>54.171</td>
        <td>23.702</td>
        <td></td>
        <td></td>
        <td></td>
        <td></td>
      </tr>
    </tbody>
  </table>
</div>

##### c. 20kHz

<p align="center"><img src="pic/PS/20kHz/20kHz-comparison.png" alt="20-comparison"></p>

<div align="center">
  <table>
    <thead>
    <tr>
    <th align="center" rowspan="2">Discrete<br>Level</th>
    <th align="center" rowspan="2">%</th>
    <th align="center" colspan="4">Observed ESU Product</th>
    <th align="center" colspan="4">RnD Implementation</th>
    </tr>
    <tr>
    <th align="center">$V_{max}$ [V]</th>
    <th align="center">$V_{min}$ [V]</th>
    <th align="center">$V_{rms}$ [V]</th>
    <th align="center">$f$ [kHz]</th>
    <th align="center">$V_{max}$ [V]</th>
    <th align="center">$V_{min}$ [V]</th>
    <th align="center">$V_{rms}$ [V]</th>
    <th align="center">$f$ [kHz]</th>
    </tr>
    </thead>
    <tbody align="right">
      <tr>
        <td></td>
        <td></td>
        <td>84.480</td>
        <td>-128.090</td>
        <td>25.387</td>
        <td>19.158</td>
        <td></td>
        <td></td>
        <td></td>
        <td></td>
      </tr>
      <tr>
        <td></td>
        <td></td>
        <td>122.210</td>
        <td>-160.120</td>
        <td>30.377</td>
        <td>19.152</td>
        <td></td>
        <td></td>
        <td></td>
        <td></td>
      </tr>
      <tr>
        <td></td>
        <td></td>
        <td>162.360</td>
        <td>-213.860</td>
        <td>32.246</td>
        <td>19.154</td>
        <td></td>
        <td></td>
        <td></td>
        <td></td>
      </tr>
      <tr>
        <td></td>
        <td></td>
        <td>179.460</td>
        <td>-249.180</td>
        <td>35.753</td>
        <td>19.152</td>
        <td></td>
        <td></td>
        <td></td>
        <td></td>
      </tr>
      <tr>
        <td></td>
        <td></td>
        <td>200.960</td>
        <td>-287.360</td>
        <td>41.550</td>
        <td>19.157</td>
        <td></td>
        <td></td>
        <td></td>
        <td></td>
      </tr>
      <tr>
        <td></td>
        <td></td>
        <td>220.260</td>
        <td>-306.89</td>
        <td>46.031</td>
        <td>19.162</td>
        <td></td>
        <td></td>
        <td></td>
        <td></td>
      </tr>
    </tbody>
  </table>
</div>

##

##
<!-- Air Core Axial Inductor
| N1  | N2  |
|----:|----:|
|  36 | 144 |
|  36 | 144 | -->

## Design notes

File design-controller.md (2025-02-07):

### 1. Sine PWM (SPWM): lookup table, timer interrupt, and LEDC
#### 1.1. Graph
The image below presents two graphs that illustrate the relationship between a sine wave and its PWM (Pulse Width Modulation) representation:
- Left Graph
<br>This graph displays a sine wave with a frequency of 500 kHz, sampled using a sawtooth waveform at a sampling frequency of 10 MHz. The sawtooth waveform serves as a reference for capturing the sine wave's shape, allowing for a detailed representation of its amplitude variations over time.

- Right Graph
<br>This graph shows the PWM output generated from the same 500 kHz sine wave, also sampled at 10 MHz. The PWM output is derived from the sampling of the sine wave using the sawtooth waveform, effectively converting the continuous sine wave into a discrete signal that can be used for various applications, such as motor control or audio signal generation.

The graphs include five distinct rows, each representing a different amplitude level of the sine wave:
- Amplitude 100%
<br>This row illustrates the full-scale representation of the sine wave, where the peak values reach the maximum output level.

- Amplitude 50%
<br>This row shows the sine wave scaled down to half of its maximum amplitude, demonstrating how the waveform's height is reduced while maintaining its shape.

- Amplitude 25%
<br>In this row, the sine wave is further scaled down to a quarter of its maximum amplitude, highlighting the diminishing height of the waveform.

- Amplitude 10%
<br>This row depicts the sine wave at a significantly reduced amplitude, showcasing the waveform's ability to represent very low signal levels while still retaining its sinusoidal characteristics.

- Amplitude 2%
<br>The final row illustrates the sine wave at just 2% of its maximum amplitude, emphasizing the precision of the PWM output even at minimal signal levels.

The comparison between the left and right graphs provides valuable insights into how the sine wave is transformed into a PWM signal. The varying amplitude levels across the five rows demonstrate the flexibility and accuracy of PWM in representing different signal strengths, making it a crucial technique in in various electronic applications.

<p align="center">
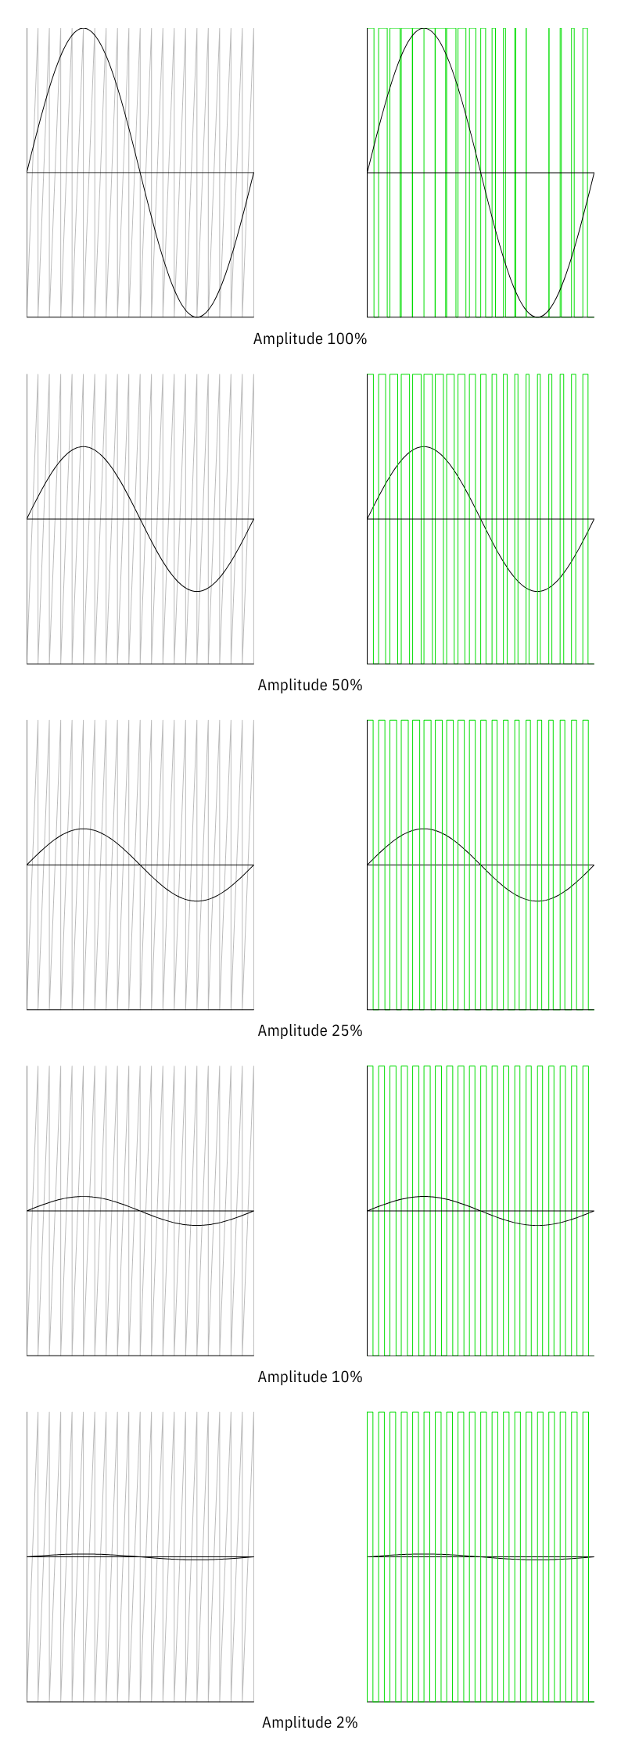
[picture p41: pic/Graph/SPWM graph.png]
spwm-graph
  
</p>
This table is based on PWM values obtained from graph drawings. These values were visually represented and may have slight variations due to the nature of graphical representation.
<p align="center">
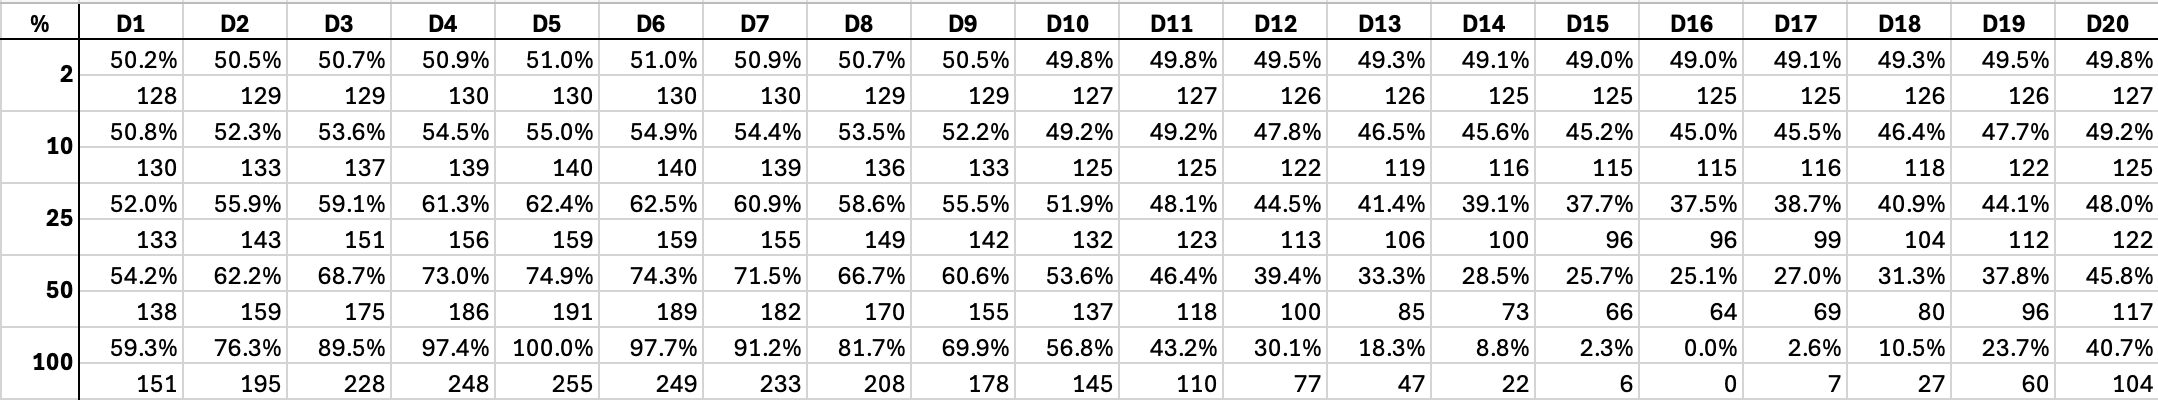
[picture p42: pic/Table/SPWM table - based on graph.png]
spwm-table
  
</p>

#### 1.2. Calculation
This table is derived from calculations based on the PWM values. It reflects the results of mathematical computations that take into account various factors such as scaling and zero crossing.
```
Scaled Value[i] = ((PWM Value[i] - Zero Crossing) x Scaling Factor ) + Zero Crossing
Scaled Value[i] = ((PWM Value[i] - 127.5) x Scaling Factor ) + 127.5
```
where PWM Value[i] is based on the 100% PWM Value from the graph
<p align="center">
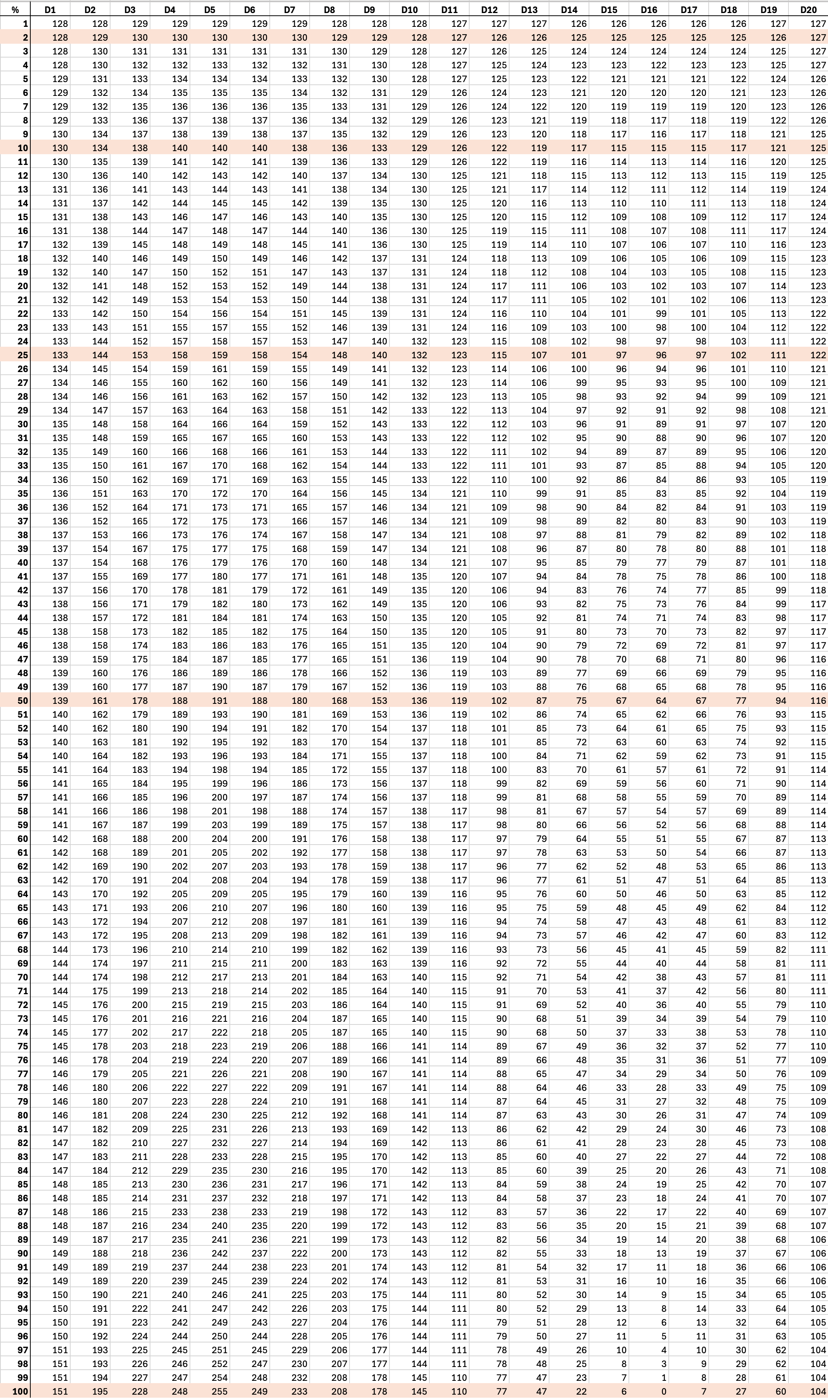
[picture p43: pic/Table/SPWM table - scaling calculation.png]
spwm-calc
  
</p>
In the current table, certain rows are highlighted in color to indicate that the values in these rows are either the same as or closely approaching the corresponding values from the previous table. This visual cue helps to quickly identify areas where the calculated PWM values align well with those derived from the graphical representation.

The proximity of values between the two tables suggests that the calculations performed in the current table effectively replicate or approximate the PWM values that were originally drawn from the graph. This is important for validating the accuracy of the calculations and ensuring that the PWM signals generated will closely match the intended design.

The alignment of values in the colored rows reinforces the reliability of the current table's calculations, indicating that the mathematical model used is consistent with the graphical data. This consistency is crucial for applications where precise PWM control is necessary.

#### 1.3. Code
This code is intended for an embedded system (like an ESP32) that generates a PWM signal based on a sine wave. The PWM signal can be adjusted in amplitude using a scale factor that can be set via serial input. The code also allows stopping the PWM signal.
##### Key Components
###### Libraries and Definitions
- `<driver/gpio.h>`:
<br>Provides functions to control General Purpose Input/Output (GPIO) pins. It allows you to set pin modes (input/output) and read/write values to/from the pins.
- `<driver/ledc.h>`:
<br>Used for configuring the LED Controller (LEDC) for PWM (Pulse Width Modulation) output. It allows you to set up timers and channels for PWM signals.
- `<driver/timer.h>`:
<br>Provides functions to configure and manage hardware timers. Timers are essential for generating periodic interrupts, which are used to update the PWM signal.
- `<math.h>`:
<br>Includes mathematical functions. Although not explicitly used in this snippet, it is often included for mathematical operations.
```cpp
#include <driver/gpio.h>
#include <driver/ledc.h>
#include <driver/timer.h>
#include <math.h>
```

- `OUTPUT_PIN`
  <br>Defines the GPIO pin number (GPIO 18) that will be used to output the PWM signal. You can change this to any other pin as needed.
- `SINE_TABLE_SIZE`
  <br>Defines the number of points in the sine wave lookup table. In this case, it is set to 20, meaning there are 20 pre-calculated values in the sine wave array.
- `SINE_WAVE_FREQUENCY`
  <br>This sets the frequency of the sine wave to 500 kHz. This is the rate at which the sine wave will be sampled and output.
```cpp
#define OUTPUT_PIN GPIO_NUM_18
#define SINE_TABLE_SIZE 20
#define SINE_WAVE_FREQUENCY 500000
```

- LEDC Timer Configuration Constants:
  - `LEDC_TIMER_CFG_SPEED_MODE`
    <br>Sets the speed mode for the LEDC timer to low speed.
  - `LEDC_TIMER_CFG_TIMER_NUM`
    <br>Specifies which timer to use (timer 0).
  - `LEDC_TIMER_CFG_DUTY_RESOLUTION`
    <br>Sets the resolution of the PWM signal to 8 bits (0-255).
  - `LEDC_TIMER_CFG_FREQ_HZ`
    <br>Sets the PWM frequency to 10 MHz.
  - `LEDC_TIMER_CFG_CLK_CFG`
    <br>Configures the clock source for the timer.
```cpp
#define LEDC_TIMER_CFG_SPEED_MODE LEDC_LOW_SPEED_MODE
#define LEDC_TIMER_CFG_TIMER_NUM LEDC_TIMER_0
#define LEDC_TIMER_CFG_DUTY_RESOLUTION LEDC_TIMER_8_BIT
#define LEDC_TIMER_CFG_FREQ_HZ 10000000
#define LEDC_TIMER_CFG_CLK_CFG LEDC_AUTO_CLK
```

- LEDC Channel Configuration Constants:
  - `LEDC_CHANNEL_CFG_CHANNEL`
    <br>Specifies which channel to use (channel 0).
  - `LEDC_CHANNEL_CFG_INTR_TYPE`
    <br>Disables interrupts for this channel.
```cpp
#define LEDC_CHANNEL_CFG_CHANNEL LEDC_CHANNEL_0
#define LEDC_CHANNEL_CFG_INTR_TYPE LEDC_INTR_DISABLE
```

- Timer Configuration Constants:
  - `TIMER_CFG_ALARM_EN`
    <br>Enables the timer alarm.
  - `TIMER_CFG_AUTO_RELOAD`
    <br>Allows the timer to automatically reload after reaching the alarm value.
  - `TIMER_CFG_COUNTER_DIR`
    <br>Sets the timer to count up.
  - `TIMER_CFG_COUNTER_EN`
    <br>Starts the timer.
  - `TIMER_CFG_INTR_TYPE`
    <br>Sets the interrupt type to level-triggered.
```cpp
#define TIMER_CFG_ALARM_EN TIMER_ALARM_EN
#define TIMER_CFG_AUTO_RELOAD TIMER_AUTORELOAD_EN
#define TIMER_CFG_COUNTER_DIR TIMER_COUNT_UP
#define TIMER_CFG_COUNTER_EN TIMER_START
#define TIMER_CFG_INTR_TYPE TIMER_INTR_LEVEL
```

- Timer Group and Index Constants:
  - `TIMER_GROUP`
    <br>Specifies the timer group to use (group 0).
  - `TIMER_IDX`
    <br>Specifies the timer index to use (timer 0).
```cpp
#define TIMER_GROUP TIMER_GROUP_0
#define TIMER_IDX TIMER_0
```

###### Sine Wave Lookup Table
This array contains 20 pre-calculated values of a sine wave, scaled to fit within the range of 0-255. Each value corresponds to a point in the sine wave, allowing for smooth PWM output. The values are derived from the sine function and scaled to match the 8-bit resolution of the PWM signal (0-255).

```cpp
const float sineTable[SINE_TABLE_SIZE] = {
  151.22, 194.57, 228.23, 248.37, 255.00, 249.14, 232.56, 208.34, 178.25, 144.84, 110.16, 76.76, 46.67, 22.44, 5.86, 0.00, 6.63, 26.78, 60.44, 103.79
};
```

###### Global Variables
- `volatile uint32_t index`
  <br>This variable keeps track of the current index in the sine wave lookup table. It is marked as `volatile` because it is modified within an interrupt service routine (ISR), ensuring the compiler does not optimize it away.
- `float scaleFactor`
  <br>This variable determines the amplitude of the PWM signal. It is initialized to 0, meaning the PWM output will be off until changed by user input.
```cpp
volatile uint32_t index = 0;
float scaleFactor = 0.0;
```

###### PWM Setup Function
This function configures the LEDC (LED Controller) for PWM output. It sets the timer, resolution, frequency, and the output pin.
- `ledc_timer_config_t timerConfig`
  <br>This structure holds the configuration for the PWM timer. The various fields are set using the defined constants for speed mode, timer number, duty resolution, frequency, and clock configuration.
- `ledc_channel_config_t channelConfig`
  <br>This structure holds the configuration for the PWM channel. The fields are set using the defined constants for speed mode, channel, interrupt type, timer selection, initial duty cycle, and GPIO pin.
The function calls `ledc_timer_config()` and `ledc_channel_config()` to apply the configurations.
```cpp
void setupPWM() {
  ledc_timer_config_t timerCfg;
  timerCfg.speed_mode = LEDC_TIMER_CFG_SPEED_MODE;
  timerCfg.timer_num = LEDC_TIMER_CFG_TIMER_NUM;
  timerCfg.duty_resolution = LEDC_TIMER_CFG_DUTY_RESOLUTION;
  timerCfg.freq_hz = LEDC_TIMER_CFG_FREQ_HZ;
  timerCfg.clk_cfg = LEDC_TIMER_CFG_CLK_CFG;
  ledc_timer_config(&timerCfg);

  ledc_channel_config_t channelCfg;
  channelCfg.speed_mode = LEDC_TIMER_CFG_SPEED_MODE;
  channelCfg.channel = LEDC_CHANNEL_CFG_CHANNEL;
  channelCfg.intr_type = LEDC_CHANNEL_CFG_INTR_TYPE;
  channelCfg.timer_sel = LEDC_TIMER_CFG_TIMER_NUM;
  channelCfg.duty = 0; // Start with 0 duty
  channelCfg.gpio_num = OUTPUT_PIN; // Set the output pin
  channelCfg.hpoint = 0;
  ledc_channel_config(&channelCfg);
}
```

###### Timer Interrupt Handler
This function is called every time the timer interrupt occurs. It updates the PWM signal based on the current sine wave value.
- `uint8_t scaledDuty`
  <br>This variable calculates the duty cycle for the PWM signal.
  <br>The formula adjusts the sine wave value to fit within the 0-255 range, scaled by the scaleFactor. The sine wave values are centered around 127.5 to ensure they fit within the PWM range.
- `ledc_set_duty()`
  <br>This function sets the duty cycle for the specified PWM channel.
- `ledc_update_duty()`
  <br>This function updates the PWM output with the new duty cycle.
- `index = (index + 1) % SINE_TABLE_SIZE`
  <br>This line increments the index to move to the next value in the sine wave table. The modulo operation ensures that the index wraps around to 0 when it reaches the end of the table, creating a continuous loop.
```cpp
void IRAM_ATTR onTimer(void* arg) {
  uint8_t scaledDuty = ((sineTable[index] - 127.5) * scaleFactor / 100) + 127.5;
  
  ledc_set_duty(LEDC_TIMER_CFG_SPEED_MODE, LEDC_CHANNEL_CFG_CHANNEL, scaledDuty);
  ledc_update_duty(LEDC_TIMER_CFG_SPEED_MODE, LEDC_CHANNEL_CFG_CHANNEL);

  index = (index + 1) % SINE_TABLE_SIZE;
}
```

###### Setup Function
Initializes serial communication for input, sets up GPIO, configures PWM, and initializes the timer.
```cpp
void setup() {
  Serial.begin(115200);
  
  gpio_set_direction(OUTPUT_PIN, GPIO_MODE_OUTPUT);

  setupPWM();

  timer_config_t config;
  config.alarm_en = TIMER_CFG_ALARM_EN;
  config.auto_reload = TIMER_CFG_AUTO_RELOAD;
  config.counter_dir = TIMER_CFG_COUNTER_DIR;
  config.counter_en = TIMER_CFG_COUNTER_EN;
  config.divider = 80;
  config.intr_type = TIMER_CFG_INTR_TYPE;

  timer_init(TIMER_GROUP, TIMER_IDX, &config);
  
  timer_set_alarm_value(TIMER_GROUP, TIMER_IDX, (80e6 / SINE_WAVE_FREQUENCY) / SINE_TABLE_SIZE);
  
  timer_enable_intr(TIMER_GROUP, TIMER_IDX);
  timer_isr_register(TIMER_GROUP, TIMER_IDX, onTimer, NULL, 0, NULL);
}
```

###### Main Loop
Continuously checks for serial input. If 's' is received, it stops the PWM by setting `scaleFactor` to 0. If a number between 1 and 100 is received, it sets the `scaleFactor` to that value divided by 100, allowing for a range of 0.01 to 1.00.
```cpp
void loop() {
  if (Serial.available()) {
    String input = Serial.readStringUntil('\n');
    if (input == "s") {
      scaleFactor = 0.0;
    } else {
      int value = input.toInt();
      if (value >= 1 && value <= 100) {
        scaleFactor = value / 100.0;
      }
    }
  }
}
```

##### How It Works
- When the program starts, it initializes the PWM and timer.
- The timer generates interrupts at a specified frequency, calling the `onTimer()` function to update the PWM signal based on the sine wave lookup table.
- The user can send commands via serial input to adjust the amplitude of the PWM signal or stop it entirely.

##### Full Code
```cpp
#include <Arduino.h>

#include <driver/gpio.h>
#include <driver/ledc.h>
#include <driver/timer.h>
#include <math.h>

// Change to your desired GPIO pin
#define OUTPUT_PIN GPIO_NUM_18
#define SINE_TABLE_SIZE 20
#define SINE_WAVE_FREQUENCY 500000

#define LEDC_TIMER_CFG_SPEED_MODE LEDC_LOW_SPEED_MODE
#define LEDC_TIMER_CFG_TIMER_NUM LEDC_TIMER_0
#define LEDC_TIMER_CFG_DUTY_RESOLUTION LEDC_TIMER_8_BIT
#define LEDC_TIMER_CFG_FREQ_HZ 10000000
#define LEDC_TIMER_CFG_CLK_CFG LEDC_AUTO_CLK

#define LEDC_CHANNEL_CFG_CHANNEL LEDC_CHANNEL_0
#define LEDC_CHANNEL_CFG_INTR_TYPE LEDC_INTR_DISABLE

#define TIMER_CFG_ALARM_EN TIMER_ALARM_EN
#define TIMER_CFG_AUTO_RELOAD TIMER_AUTORELOAD_EN
#define TIMER_CFG_COUNTER_DIR TIMER_COUNT_UP
#define TIMER_CFG_COUNTER_EN TIMER_START
#define TIMER_CFG_INTR_TYPE TIMER_INTR_LEVEL

#define TIMER_GROUP TIMER_GROUP_0
#define TIMER_IDX TIMER_0

// Predefined sine wave lookup table (scaled to 0-255)
const float sineTable[SINE_TABLE_SIZE] = {
  151.22, 194.57, 228.23, 248.37, 255.00, 249.14, 232.56, 208.34, 178.25, 144.84, 110.16, 76.76, 46.67, 22.44, 5.86, 0.00, 6.63, 26.78, 60.44, 103.79
};

volatile uint32_t index = 0;

// Set amplitude scale to 100%
float scaleFactor = 0.0;

void setupPWM() {
  // Configure the LEDC for PWM
  ledc_timer_config_t timerCfg;
  timerCfg.speed_mode = LEDC_TIMER_CFG_SPEED_MODE;
  timerCfg.timer_num = LEDC_TIMER_CFG_TIMER_NUM;
  // 8-bit resolution
  timerCfg.duty_resolution = LEDC_TIMER_CFG_DUTY_RESOLUTION;
  // Set PWM frequency to 10 MHz
  timerCfg.freq_hz = LEDC_TIMER_CFG_FREQ_HZ;
  timerCfg.clk_cfg = LEDC_TIMER_CFG_CLK_CFG;
  ledc_timer_config(&timerCfg);

  ledc_channel_config_t channelCfg;
  channelCfg.speed_mode = LEDC_TIMER_CFG_SPEED_MODE;
  channelCfg.channel = LEDC_CHANNEL_CFG_CHANNEL;
  channelCfg.intr_type = LEDC_CHANNEL_CFG_INTR_TYPE;
  channelCfg.timer_sel = LEDC_TIMER_CFG_TIMER_NUM;
  // Start with 0 duty
  channelCfg.duty = 0;
  // Set the output pin
  channelCfg.gpio_num = OUTPUT_PIN;
  channelCfg.hpoint = 0;
  ledc_channel_config(&channelCfg);
}

void IRAM_ATTR onTimer(void* arg) {
  // Scale the duty cycle based on the scale factor
  uint8_t scaledDuty = (( sineTable[index] - 127.5 ) * scaleFactor / 100 ) + 127.5;
  
  ledc_set_duty(LEDC_TIMER_CFG_SPEED_MODE, LEDC_CHANNEL_CFG_CHANNEL, scaledDuty);
  ledc_update_duty(LEDC_TIMER_CFG_SPEED_MODE, LEDC_CHANNEL_CFG_CHANNEL);

  // Loop through the sine table
  index = (index + 1) % SINE_TABLE_SIZE; // Updated to use 20 points
}

void setup() {
  Serial.begin(115200);
  
  // Initialize GPIO
  gpio_set_direction(OUTPUT_PIN, GPIO_MODE_OUTPUT);

  // Setup PWM
  setupPWM();

  // Configure the timer
  timer_config_t config;
  config.alarm_en = TIMER_CFG_ALARM_EN;
  config.auto_reload = TIMER_CFG_AUTO_RELOAD;
  config.counter_dir = TIMER_CFG_COUNTER_DIR;
  config.counter_en = TIMER_CFG_COUNTER_EN;
  // Set the timer divider for 1 MHz
  config.divider = 80; // 80 MHz / 80 = 1 MHz
  config.intr_type = TIMER_CFG_INTR_TYPE;

  timer_init(TIMER_GROUP, TIMER_IDX, &config);
  
  // Set the timer alarm value for 500 kHz
  timer_set_alarm_value(TIMER_GROUP, TIMER_IDX, (80e6 / SINE_WAVE_FREQUENCY) / SINE_TABLE_SIZE);
  
  // Enable the timer interrupt
  timer_enable_intr(TIMER_GROUP, TIMER_IDX);
  timer_isr_register(TIMER_GROUP, TIMER_IDX, onTimer, NULL, 0, NULL);
}

void loop() {
  // Main loop can be empty or used for other tasks
  if (Serial.available()) {
    String input = Serial.readStringUntil('\n'); // Read until newline
    if (input == "s") {
      // Stop PWM
      scaleFactor = 0.0; // Set scaleFactor to 0 to stop PWM
    } else {
      // Convert input to scaleFactor
      int value = input.toInt(); // Convert string to integer
      if (value >= 1 && value <= 100) {
        scaleFactor = value / 100.0; // Set scaleFactor as a decimal
      }
    }
  }
}
```

#### 1.4. Measurement

### 2. Sine PWM (SPWM): MCPWM
#### 2.1 Overview

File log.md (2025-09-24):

2025-09-23
- HMI: feat/SP-address-control untuk center alignment text [Done]

2025-09-19

2025-09-18
- Rework UI: main, menu, save/load user profiles [In Progress]
- HMI: feat/center-alignment-text [In Progress]
- firmware coding: feat/adjust-position-text [In Progress]

2025-09-17
- firmware coding: feat/persistent-data-storage menggunakan littlefs untuk read/write memory [Done]
- HMI: feat/save-load-profiles [Done]
- Refactor firmware code: config, data_manager, hardware_control, display_comm, main [Done]
- Rework UI: main, menu, save/load user profiles [In Progress]

2025-09-16
- firmware coding: feat/persistent-data-storage menggunakan littlefs untuk read/write memory [In Progress]
- HMI: feat/save-load-profiles [In Progress]

2025-09-12
- firmware coding: feat/persistent-data-storage menggunakan littlefs untuk read/write memory [In Progress]
- HMI: feat/save-load-profiles [In Progress]

2025-09-11
- firmware coding: feat/read-data-frame [In Progress]
- firmware coding: feat/persistent-data-storage menggunakan littlefs untuk read/write memory [In Progress]

2025-09-10
- HMI: feat/incremental-adjustment [Need Review]
- HMI: feat/button-effect [Need Review]

2025-09-09
- HMI: desain UI [Need Review]
- HMI: feat/set-vp-address [Need Review]

2025-09-08
- HMI: desain UI [In Progress]

2025-09-05
- HMI: desain UI [In Progress]

2025-09-04
- firmware coding: feat/buzzer [In Progress]

2025-09-03
- firmware coding: feat/crc16_ibm [In Progress]
- firmware coding: feat/assemble-data-frame [In Progress]

2025-09-02
- Menulis tabel komparasi output scope (Rload 500Ω) [Need Review]
- Desain ESU-UI page, button, icon [In Progress]

2025-09-01
- Firmware coding: feat/return-electrode-monitoring [Need Review]
- Menulis tabel komparasi output scope (Rload 500Ω) [In Progress]

2025-08-29
- Menulis tabel komparasi output scope (Rload 500Ω) [In Progress]

2025-08-26
- Supplier inquiry untuk HMI 7" (TN/IPS) dan sejenisnya [Done]
- Desain dan kalkulasi LC filter untuk frekuensi 100kHz dengan Rload 500Ω (monopolar) [Done]
- Desain dan kalkulasi LC filter untuk frekuensi 400kHz dengan Rload 500Ω (monopolar) [Done]

2025-08-25
- Firmware coding: feat/control-relay [Need Review]
- Firmware coding: fix/PWM-25khz-timing untuk skala 0-100W dengan resolusi 800 step per modulasi (100 step 50% duty cycle untuk 100W, compatible transformer 100kHz) [Done]
- Firmware coding: fix/PWM-20khz-timing untuk skala 0-100W dengan resolusi 1000 per modulasi (100 step 50% duty cycle untuk 100W, compatible transformer 100kHz) [Done]

2025-08-22
- create/PCB ESU-XF add transformer switching relay [Dome]
- fix/PCB ESU-Main dioda TVS dengan Vbr=137V, Vc=179V, Ipp=10x1000µs (A) [Done]
- Intensive switching stress test untuk menguji ketahanan dioda TVS baru [Need Reqiew]
- Literature review IEC 60601-1 3rd Edition 2005 [In Progress]

2025-08-21
- create/PCB ESU-XF add transformer switching relay [In Progress]

2025-08-20
- Desaiin dan kalkulasi transformer 100kHz untuk support modulasi 25kHz (4 slot RMT: 1 pulse 3 off) dan 20kHz (5 slot RMT: 1 pulse 4 off) [Done]
- Troubleshoot Dioda TVS ESU-Main meledak saat long firing [Done]
- create/PCB ESU-XF add transformer switching relay [In Progress]

2025-08-19
- feat/PCB ESU-CTL add trace relay transformer 2 [Done]
- feat/PCB ESU-PS add trace relay transformer 2 [Done]
- Desaiin dan kalkulasi transformer 100kHz untuk support modulasi 25kHz (4 slot RMT: 1 pulse 3 off) dan 20kHz (5 slot RMT: 1 pulse 4 off) [In Progress]

2025-08-14
- Menulis tabel komparasi output scope [Done]

2025-08-13
- Menulis tabel komparasi output scope [In Progress]

2025-08-12
- Coil winding hasil desain LC Filter [In Progress] [2/4]

2025-08-11
- Desain dan kalkulasi induktor sesuai dengan hasil desain LC Filter [Done]
- Coil winding hasil desain LC Filter [In Progress] [1/4]

2025-08-08
- Desain dan kalkulasi induktor sesuai dengan hasil desain LC Filter [In Progress]

2025-08-07
- Design Rule Check PCB ESU-CTL dengan standar manufaktur Spectra [Done]
- rev/PCB ESU-XF re-placement dan retracing menyesuaikan komponen tersedia sesuai hitungan LC filter [Done]
- Request PO kompoenen PCB ESU-CTL dan LC Filter [In Progress]

2025-08-06
- feat/PCB ESU-PS: retracing dengan faraday shield untuk mengurangi paracitic capacitance (EMC) [Done]
- List BoM PCB ESU-CTL [Done]
- Design Rule Check PCB ESU-CTL dengan standar manufaktur Spectra [In Progress]

2025-08-05
- feat/PCB ESU-CTL: retracing dengan faraday shield untuk mengurangi paracitic capacitance (EMC) [Done]

2025-08-04
- feat/PCB ESU-CTL: retracing dengan faraday shield untuk mengurangi paracitic capacitance (EMC) [In Progress]

2025-08-01
- feat/PCB ESU-CTL: add relay untuk driver MOSFET [Need Review]

2025-07-31
- Winding bipolar toroidal core transformer sesuai kalkulasi baru menggunakan stranded wire 0.5 [Done]

2025-07-30
- Prototyping controller: rangkaian Monopolar Switch Detection [Done] 
- Firmware coding: feat/Monopolar Switch Detection [Need Review]
- Firmware coding: feat/integrasi Monopolar Switch Detection dengan Foot Switch [Need Review]

2025-07-29
- Firmware coding: feat/foot switch [Need Review]
- Firmware coding: feat/Serial Communication untuk setting mode dan duty cycle [Done]
- Function test: foot switch [Need Review]

2025-07-28
- Prototyping controller: rangkaian foot switch [Done]

2025-07-25
- Membuat bobbin induktor untuk LC filter [Done]

2025-07-24
- Membuat bobbin induktor untuk LC filter [In Progress]

2025-07-23
- Literature review untuk High Frequency AC current [Skin Effect dan Proximity] [Done]
- Literature review untuk EMC dan EMI EMS Shielding [Done]
- Menulis dokumnetasi dan penyesuaian desain Toroidal Transformer dan induktor pada LC filter [Done]

2025-07-22
- Literature review untuk High Frequency AC current [Skin Effect dan Proximity] [In Progress]

2025-07-17
- Rencana integrasi REM dan MSD [Done]
- Menulis dokumentasi desain Bipolar toroidal core transformer [Done]

2025-07-16
- Prototyping controller: integrasi power supply 12V dan 5V [Done]
- Menulis dokumentasi desain Bipolar toroidal core transformer [In Progress]

2025-07-15
- PCB layout Transformer + LC Filter [Done]
- Menulis dokumentasi desain LC Filter [Done]
- Menulis dokumentasi desain Bipolar toroidal core transformer [In Progress]

2025-07-14
- Coil winding untuk LC filter (multilayer air core inductor 29µH)

2025-07-10
- Kalkulasi LC Filter untuk resonansi 400kHz Q 0.707 (L=29µH, C=2.7nF, -3.32dB @ ƒ=402.387kHz cut-off)

2025-07-09
- Literature Review untuk LC filter vs Frequency Response

2025-07-08
- Literature Review untuk LC filter Type-1 Butterworth

2025-07-04
- Buat komparasi transformer bawaan (Bipolar dan Monopolar) dengan transformer buatan [Done]
- Buat komparasi induktor bawaan bipolar dengan induktor buatan [In Progress]

2025-07-03
- Fix PWM loop enamble timing issue [Done]

2025-07-02
- Winding ferrite core ETD35 transformer bipolar [In Review]
- Uji ferrite core ETD35 transformer bipolar [In Review]

2025-07-01
- Winding ferrite core ETD35 transformer bipolar [In Progress]
- Uji ferrite core ETD35 transformer bipolar [In Progress]

2025-07-30
- Winding ferrite core ETD35 transformer bipolar [In Progress]
- Uji ferrite core ETD35 transformer bipolar [In Progress]

2025-06-19
- Uji coil air core EE25 dengan kawat 1 untuk LC filter bipolar menggunakan tegangan 72V [Need Review]
- Uji transformer dan coil monopolar ke resistor dummy 500R [Need Review]
- Uji transformer dan coil bipolar ke resistor dummy 500R [Need Review]

2025-06-18
- Uji air core transformer EE35 dengan kawat 1 Bipolar dan Monopolar menggunakan tegangan 72V [Done]
- Uji coil ferrite core EE25 dengan kawat 1 untuk LC filter monopolar menggunakan tegangan 72V [Need Review]

2025-06-17
- Winding coil ferrite core EE25 dengan kawat 1 untuk LC filter monopolar [Done]
- Uji coil ferrite core EE25 dengan kawat 1 untuk LC filter monopolar menggunakan tegangan 36V [Need Review]

2025-06-16
- Winding air core transformer EE35 dengan kawat 1 Bipolar dan Monopolar [Done]
- Uji air core transformer EE35 dengan kawat 1 Bipolar dan Monopolar menggunakan tegangan 36V [Done]
- Integrasi air core transformer EE35 Bipolar dengan LC Filter bawaan [Done]

2025-06-13
- Uji air core transformer primary EE25 dengan kawat 0.5 [Need Review]
- Uji air core transformer primary 12.7 x 16.8 x 16.8 dengan kawat 0.5 [Need Review]

2025-06-12
- Coil winding air core transformer primary EE25 dengan kawat 0.5 [In Progress]
- Coil winding air core transformer primary 12.7 x 16.8 x 16.8 dengan kawat 0.5 [In Progress]

2025-06-11
- Uji ferrite core transformer EE25 [Done]
- Uji air core transformer primary EE25 untuk output monopolar [In Progress]
- Coil winding air core transformer secondary EE25 dengan kawat 0.8 [In Progress]
- Coil winding air core transformer primary 12.7 x 16.8 x 16.8 dengan kawat 0.8 [In Progress]
- Troubleshooting the drain-source protection failure [Need Review]

2025-06-10
Uji toroidal ferrite core transformer primer untuk output bipolar [In Progress]

2025-06-05
- Integrasi Controller dengan ESU-PS [In Progress]
- Capture sinyal osilasi MOSFET dengan VDS 36V [In Progress]

2025-06-04
- Integrasi Controller dengan ESU-PS [In Progress]
- Capture sinyal osilasi MOSFET dengan VDS 12V [In Progress]

2025-06-03
- Integrasi Controller dengan ESU-PS [In Progress]
- Uji MOSFET driver [Done]

2025-06-02
- Uji proteksi tegangan input PCB ESU-PS [Done]
- Troubleshooting the floating ground failure [Done]

2025-05-21
- PCBA Power Stage [In Progress]
- Desain PCB ESU-Controller [In Progress]

2025-05-20
- PCBA Power Stage [In Progress]

2025-05-16
- Desain PCB ESU-Controller [In Progress]

2025-05-14
- Winding koker 7 [Done]

2025-05-09
- PO PCB [Done]
- Kalkulasi Rectangular Air Inductor 7 dan 8.8 [Done]
- Winding koker 8.8 [Done]

2025-05-06
- Menulis dokumentasi PWM Generator [Done]
- Rework PCB ESU-PS untuk kapasitor snap-in besar [Done]
- PO PCB [In Progress]

2025-05-05
- Modulate PWM, 18 pulse per trigger 2 pulse 0% (blend cut 1) [Done]
- Modulate PWM, 17 pulse per trigger 3 pulse 0% (blend cut 2) [Done]
- Generate PWM untuk 25kHz resolusi 400 discrete level (coag spray) [Done]
- Generate PWM untuk 20kHz resolusi 500 discrete level (coag forced) [Done]
- Menulis dokumentasi PWM Generator [In Progress]

2025-05-02
- LEDC PWM 400kHz resolusi 6-bit [Done]
- RMT (Remote Control) module 400kHz resolusi 200 level [Done]

2025-04-30
- LEDC PWM 400kHz resolusi 6-bit [In Progress]

2025-04-29
- Design Rule Check berdasarkan standar spectra + Rev [Done]
- Design & Calculation: bipolar power stage output inductor [Done]
- Design Jig Inductor winding [In Progress]
- Order cetak PCB [To Do]
- Inductor winding [To Do]

2025-04-28
- Layout PCB ESU-PS [Done]
- List BoM PCB ESU-PS [Done]
- Design Rule Check berdasarkan standar spectra + Rev [In Progress]

2025-04-17
- Layout PCB ESU-PS [In Progress]
- Soldering Signal Amplifier LM358 [Done]
- Test Signal Amplifier LM358 [Done]

2025-04-16
- Layout PCB ESU-PS [In Progress]

2025-04-15
- Fix 555 support 12V [Done]
- Test PCB ESU-REM (Resistance min, max, high impedance) [Done]
- Fix PCB ESU-REM, tegangan tidak kembali ke seharusnya setelah high impedance [Done]

2025-04-14
- Test coil horizontal di ESU-MSD [Done]
- Soldering Signal amplifier LM358 [In Progress]

2025-04-11
- Coil winding (model horizontal) [Done]
- Test coil horizontal di ESU-REM [Done]

2025-04-10
- Revisi PCB ESU-MSD (coil horizontal) [Done]
- Revisi PCB ESU-REM (coil horizontal + LM358) [Need Review]

2025-04-09
- Coil winding (model horizontal) [In Progress]
- Tes op amp ESU-REM [In Progress]

2025-03-26
- Coil winding [In Progress]

2025-03-25
- PCBA ESU-MSD [In Progress]
- PCBA ESU-REM [In Progress]
- Tes osilasi [Done]

2025-03-24
- NVeCam: improve booting performance [Done]
- Clonning Image [Done]
- PCBA ESU-MSD [In Progress]
- PCBA ESU-REM [In Progress]

2025-03-21
- NVeCam rework/settings-set-prompt [Need Review]
- Clonning Image [Done]

2025-03-20
- NVeCam feat/settings-set-prompt [Need Review]

2025-03-19
- Layout PCB ESU-PS [In Progress]
- NVeCam feat/settings-wifi-fe [Need Review]
- NVeCam feat/settings-wifi-be [Need Review]

2025-03-18
- Layout PCB ESU-PS [In Progress]

2025-03-17
- Layout PCB ESU-PS [In Progress]

2025-03-05
- List BoM PCB ESU-REM [Done]
- Revisi PCB ESU-REM [Done]
- Design Rule Check berdasarkan standar spectra + Rev [Done]
- Order cetak PCB [Done]

2025-03-03
- List BoM PCB ESU-REM [In Progress]
- Revisi PCB ESU-REM [In Progress]

2025-02-28
- List BoM PCB ESU-REM [In Progress]
- List BoM PCB ESU-MSD [Done]
- Revisi PCB ESU-REM [In Progress]
- Penyesuaian layout PCB ESU-MSD dengan komponen tersedia [Done]

2025-02-27
- List BoM PCB ESU-REM [In Progress]
- List BoM PCB ESU-MSD [In Progress]
- Penyesuaian layout PCB ESU-REM dengan komponen tersedia [In Progress]
- Penyesuaian layout PCB ESU-MSD dengan komponen tersedia [In Progress]

2025-02-26
- List BoM PCB ESU-REM [In Progress]
- List BoM PCB ESU-MSD [In Progress]
- Penyesuaian layout PCB ESU-REM dengan komponen tersedia [In Progress]
- Penyesuaian layout PCB ESU-MSD dengan komponen tersedia [In Progress]
- Menulis dokumentasi desain toroidal core isolation transformer ESU-MSD [Need Review]

2025-02-25
  Layout PCB ESU-MSD [Done]

2025-02-24
- Layout PCB ESU-REM [Done]
- Layout PCB ESU-MSD [In Progress]

2025-02-21
<br>Layout PCB ESU-REM [In Progress]

2025-02-20
<br>Tes rangkaian controller dan mainboard ESU:
- Rekam sinyal input vs output transformer Return Electrode detection [Done]
- Analisa cara kerja rangkaian Return Electrode detection berdasarkan sinyal input-output transformer dan gambar reverse Engineering mainboard ESU [Need Review]
- Revisi gambar reverse engineering mainboard ESU [Need Review]

<br>Menulis dokumentasi reverse engineering ESU
- Penghitungan toroidal core transformer monopolar probe switch [Need Review]

2025-02-19
<br>Tes rangkaian mainboard ESU:
- Rekam sinyal input vs output transformer monopolar probe switch detection [Done]
- Analisa cara kerja rangkaian monopolar probe switch detection berdasarkan sinyal timer 555, input-output transformer dan gambar reverse Engineering mainboard ESU [Need Review]
- Revisi gambar reverse engineering mainboard ESU [Need Review]

2025-02-18
<br>Tes rangkaian controller dan mainboard ESU:
- Rekam sinyal input vs output driver MOSFET [In Progress]
- Rekam sinyal output driver MOSFET vs output power stage [In Progress]
- Analisa cara kerja generator ESU berdasarkan sinyal input-output power stage dan gambar reverse Engineering mainboard ESU [Need Review]
- Revisi gambar reverse engineering mainboard ESU [Need Review]

2025-02-17
<br>Tes rangkaian controller ESU:
- Rekam sinyal input - Monopolar cut (pure, blend1, blend2) [Done]
- Rekam sinyal input - Monopolar coag (spray, forced) [Done]
- Rekam sinyal input - Bipolar standard [Done]

2025-02-12
<br>Tes rangkaian mainboard ESU menggunakan osiloskop digital:
- Rekam sinyal output - Monopolar cut (pure, blend1, blend2) [Done]
- Rekam sinyal output - Monopolar coag (spray, forced) [Done]
- Rekam sinyal output - Bipolar standard [Done]

2025-02-11
<br>Tes rangkaian mainboard ESU menggunakan osiloskop digital:
- Rekam sinyal output - Monopolar cut (pure, blend1, blend2) [In Progress]
- Rekam sinyal output - Monopolar coag (spray, forced) [To Do]
- Rekam sinyal output - Bipolar standard [To Do]

2025-02-10
<br>Alternatif PWM generator menggunakan MCPWM sebagai SPWM generator:
- Membuat model matematis sinewave berdasarkan variable amplitude, ƒ mod, ƒ carrier [Need Review]
- coding MCPWM sebagai SPWM generator menggunakan fungsi timer interrupt [Need Review]
- Uji fungsi MCPWM sebagai SPWM generator menggunakan oscilloscope [To Do]

2025-02-07
<br>https://yopiediy.xyz/esp32-mcpwm-as-spwm-generator/
<br>Perancangan hardware PWM generator:
- coding untuk generate PWM 10MHz that simulates a sine wave 500kHz menggunakan metode lookup table, timer interrupt, dan LEDC timer [Need Review]
- Implementasi scaling SPWM calculation formula ke code menggunakan controller BPI-Leaf-S3 [Need Review]
- Menulis dokumentasi design-controller: SPWM generator code [Need Review]
- Uji fungsi scaling SPWM menggunakan oscilloscope [To Do]

  Alternatif PWM generator menggunakan MCPWM sebagai PWM generator
- Mathematical Modeling dan implementation code [In Progress]

2025-02-06
<br>Perancangan hardware PWM generator:
- coding untuk generate PWM 10MHz that simulates a sine wave 500kHz [In Progress]
- Membuat kalkulasi scaling SPWM untuk varying amplitude dari 1% sampai 100% berdasarkan hasil ukur grafik SPWM amplitude 100% [Done]
- Analisa perbandingan hasil hitung terhadap hasil ukur grafik [Done]
- Menulis dokumentasi design-controller: grafik, datatable, dan analisa hitungan scaling SPWM calculation formula [Bone]
- Implementasi scaling SPWM calculation formula ke code [To Do]

2025-02-05
<br>Perancangan hardware PWM generator:
- coding untuk generate PWM 10MHz that simulates a sine wave 500kHz [In Progress]
- Buat grafik SPWM 10MHz untuk amplitude 100%, 50%, 25%, 10%, 2% sebagai acuan [Done]
- Mengukur Duty Cycle dari grafik SPWM [Done]

2025-02-04
<br>Rencana alternatif pengukuran daya output ESU:
- Referensi produk Current Transformer high frequency [In Progress]
- Referensi pengukuran Current Transformer high frequency [Done]

  Perancangan hardware PWM generator:
- coding untuk generate PWM 10MHz that simulates a sine wave 500kHz [In Progress]

2025-02-03
<br>Rencana alternatif pengukuran daya output ESU:
- Referensi produk osiloskop digital: Hantek, Rigol [Done]
- Referensi produk Current Transformer high frequency [In Progress]
- Referensi pengukuran Current Transformer high frequency [To Do]

2025-01-31
<br>Menulis document testing ESU:
<br>Output Power Stage Measurement Report
- Menyusun gambar untuk komparasi [Done]
- Hitung frekuensi modulasi [Need Review]
- Hitung tegangan maksimum [In Progress]

2025-01-24
<br>Tes rangkaian mainboard ESU:
- Setup generator output test connection - Bipolar & Monopolar [Done]
- Rekam sinyal output - Bipolar standard [Done]
- Rekam sinyal output - Monopolar cut (pure, blend1, blend2) [Done]
- Rekam sinyal output - Monopolar coag (spray, forced) [Done]

2025-01-23
<br>Tes rangkaian mainboard ESU:
- Setup oscillator test coonection
- Rekam sinyal input MOSFET Driver / Output Controller dengan berbagai mode cut dan coag [Need Review]
- Setup generator output test connection - Bipolar [In Progress]

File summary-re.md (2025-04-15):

## Performance Test
### A. Monopolar
#### A.1 Cut
##### A.1.1 Pure Cut
- Input
- Output
<br>The image illustrates the output scope for the Pure Cut operation at the power stage output in three different load. It provides a detailed view of the waveform characteristics and performance metrics associated with the pure cut process, highlighting the key features and behavior of the signal during this operation.
  - Left Scope:<br>This represents the output for Pure Cut operation with 100Ω load.
  - Middle Scope:<br>This represents the output for Pure Cut operation with 500Ω load.
  - Right Scope:<br>This represents the output for Pure Cut operation with 600Ω load.

> [!NOTE]
> The oscilloscope setup uses a passive probe with a 10x attenuation factor and a voltage divider of 1/10, resulting in a total measurement factor of 100.

<p align="center">
  pure-cut
</p>

<!-- _Signal Frequency:_
```
T = 5µs ÷ 2.5 wave
T = 2µs

f = 1 ÷ 2µs
f = 500kHz
``` -->

_Peak Voltage (Vp) and Current (I):_
<br>The Vp is calculated by taking the vertical division setting on the oscilloscope and multiplying it by 100 (total measurement factor), along with the vertical scale of 1V per division (1V/div).

> [!NOTE]
> In this analysis, the peak voltage (Vp) is calculated using a simple method that involves measuring the vertical divisions of the peak-to-peak voltage (Vpp) on the oscilloscope. To begin, one observes the oscilloscope display and counts the total number of vertical divisions that the waveform spans from the maximum positive peak to the maximum negative peak, which provides the peak-to-peak voltage (Vpp). The peak voltage (Vp) is then determined by dividing the Vpp by two, expressed mathematically as `Vp = Vpp ÷ 2`.<br><br>While this method is straightforward and convenient, it is important to recognize its limitations, particularly when dealing with asymmetric signals. In an asymmetric waveform, the positive and negative peaks may not be equal in magnitude. Consequently, simply dividing the Vpp by two assumes that the waveform is symmetrical around the zero voltage line, which is often not the case. This approach can lead to significant errors in the calculated peak voltage, as it does not account for the actual heights of the individual peaks. For instance, if the positive peak is much higher than the negative peak, the calculated Vp will not accurately reflect the true maximum voltage deviation from zero.

<!-- | Power | Vp     | I      |
| ----: | -----: | -----: |
|    5W |    50V |        | 0.5
|   10W |    75V |        | 0.75
|   20W |   100V |        | 1
|   30W |   115V |        | 1.15
|   40W |   130V |        | 1.3
|   50W |   150V |        | 1.5
|   60W |   160V |        | 1.6
|   70W |   165V |        | 1.65
|   80W |   175V |        | 1.75
|   90W |   180V |        | 1.8
|  100W |   185V |        | 1.85 -->

- Input and Output
<br>The image illustrates the input and output scope for the Pure Cut operation at the controller and power stage output. It provides a detailed view of the waveform characteristics and performance metrics associated with the pure cut process, highlighting the key features and behavior of the signal during this operation.
<p align="center">
  <img src="pic/Reverse%20Engineering/scope%20-%20generator%20output%20-%20new/monopolar/cut/pure-io.png" alt="pure-io">
</p>

##### A.1.2 Blend Cut
- Input
- Output
<br>The image displays three output scopes for Pure Cut operation and Blend Cut operations at the power stage output:
  - Left Scope:<br>This represents the output for Pure Cut. It illustrates the waveform characteristics and performance metrics associated with the pure cut operation.
  - Middle Scope:<br>This represents the output for Blend Cut 1. It showcases the waveform details and performance metrics related to the Pure Cut operation, allowing for a comparative analysis between the Pure Cut and Blend Cut 1.
  - Right Scope:<br>This represents the output for Blend Cut 2. It showcases the waveform details and performance metrics related to the second cut blend operation, allowing for a comparative analysis between the two blends.

> [!NOTE]
> The oscilloscope setup uses a passive probe with a 10x attenuation factor and a voltage divider of 1/10, resulting in a total measurement factor of 100.

<p align="center">
  <img src="pic/Reverse%20Engineering/scope%20-%20generator%20output%20-%20new/monopolar/cut/pure-blend-1-2.png" alt="cut-blend">
</p>

<!-- _Signal Frequency:_
```
T = 10µs ÷ 5
T = 2µs

f = 1 ÷ 2µs
f = 500kHz
``` -->

_Modulation Frequency:_
```
T = 10µs * 4.8 DIV
T = 48µs

f = 1 ÷ 48µs
f = 20.8kHz
```

_Blend Cut 1 Modulation Duty Cycle:_
```
Duty Cycle = 4.2 DIV ÷ 4.8 DIV x 100%
Duty Cycle = 87.50%
```

_Blend Cut 2 Modulation Duty Cycle:_
```
Duty Cycle = 3.8 DIV ÷ 4.8 DIV x 100%
Duty Cycle = 79.17%
```

_Peak Voltage (Vp) and Current (I):_
<br>The Vp is calculated by taking the vertical division setting on the oscilloscope and multiplying it by 100 (total measurement factor), along with the vertical scale of 1V per division (1V/div).

> [!NOTE]
> In this analysis, the peak voltage (Vp) is calculated using a simple method that involves measuring the vertical divisions of the peak-to-peak voltage (Vpp) on the oscilloscope. To begin, one observes the oscilloscope display and counts the total number of vertical divisions that the waveform spans from the maximum positive peak to the maximum negative peak, which provides the peak-to-peak voltage (Vpp). The peak voltage (Vp) is then determined by dividing the Vpp by two, expressed mathematically as `Vp = Vpp ÷ 2`.<br><br>While this method is straightforward and convenient, it is important to recognize its limitations, particularly when dealing with asymmetric signals. In an asymmetric waveform, the positive and negative peaks may not be equal in magnitude. Consequently, simply dividing the Vpp by two assumes that the waveform is symmetrical around the zero voltage line, which is often not the case. This approach can lead to significant errors in the calculated peak voltage, as it does not account for the actual heights of the individual peaks. For instance, if the positive peak is much higher than the negative peak, the calculated Vp will not accurately reflect the true maximum voltage deviation from zero.

<!-- | Power | Vp Blend 1 | I Blend 1 | Vp Blend 2 | I Blend 2 |
| ----: | ---------: | --------: | ---------: | --------: |
|   10W |        70V |           |        80V |           | 0.7 , 0.8
|   20W |       100V |           |       100V |           | 1   , 1
|   30W |       120V |           |       120V |           | 1.2 , 1.2
|   40W |       130V |           |       140V |           | 1.3 , 1.4
|   50W |       150V |           |       160V |           | 1.5 , 1.6
|   60W |       160V |           |       170V |           | 1.6 , 1.7
|   70W |       180V |           |       180V |           | 1.8 , 1.8
|   80W |       190V |           |       190V |           | 1.9 , 1.9
|   90W |       195V |           |       195V |           | 1.95, 1.95
|  100W |       200V |           |       200V |           | 2   , 2 -->

#### A.2 Coag
##### A.2.1 Spray
- Input & Output
<br>The image displays two output scopes for Spray Coagulation operations at the power stage output:
  - Left Scope:<br>This represents the output for the Spray Coagulation operation at the controller. It illustrates the waveform characteristics and performance metrics associated with the coag spray process, highlighting its unique features.
  - Right Scope:<br>This represents the output for the Spray Coagulation operation at the power stage. It showcases the waveform details and performance metrics related to the coag spray process, allowing for a comparative analysis between the two stages.

> [!NOTE]
> The oscilloscope setup uses a passive probe with a 10x attenuation factor and a voltage divider of 1/10, resulting in a total measurement factor of 100.

<p align="center">
  <img src="pic/Reverse%20Engineering/scope%20-%20generator%20output%20-%20new/monopolar/coag/spray/monopolar-coag-spray-io.png" alt="coag-spray">
</p>

_Spray Coag Modulation Frequency:_
```
T = 42.2µs

f = 1 ÷ 42.2µs
f = 23.6kHz
```

_Spray Coag Duty:_
| Power (W) | Duty (%)  |
| --------: | --------: |
|        10 |       3.3 |
|        20 |       6.2 |
|        30 |       8.1 |
|        40 |       9.5 |
|        50 |      10.9 |
|        60 |      12.3 |
|        70 |      13.7 |
|        80 |      15.2 |
|        90 |      16.1 |

_Peak Voltage (Vp) and Current (I):_
<br>The Vp is calculated by taking the vertical division setting on the oscilloscope and multiplying it by 100 (total measurement factor), along with the vertical scale of 1V per division (1V/div).

> [!NOTE]
> In this analysis, the peak voltage (Vp) is calculated using a simple method that involves measuring the vertical divisions of the peak-to-peak voltage (Vpp) on the oscilloscope. To begin, one observes the oscilloscope display and counts the total number of vertical divisions that the waveform spans from the maximum positive peak to the maximum negative peak, which provides the peak-to-peak voltage (Vpp). The peak voltage (Vp) is then determined by dividing the Vpp by two, expressed mathematically as `Vp = Vpp ÷ 2`.<br><br>While this method is straightforward and convenient, it is important to recognize its limitations, particularly when dealing with asymmetric signals. In an asymmetric waveform, the positive and negative peaks may not be equal in magnitude. Consequently, simply dividing the Vpp by two assumes that the waveform is symmetrical around the zero voltage line, which is often not the case. This approach can lead to significant errors in the calculated peak voltage, as it does not account for the actual heights of the individual peaks. For instance, if the positive peak is much higher than the negative peak, the calculated Vp will not accurately reflect the true maximum voltage deviation from zero.

<!-- | Power | Vp Spray  | I Spray | Vp  Forced | I Forced |
| ----: | --------: | ------: | ---------: | -------: |
|    5W |           |         |            |          |
|   10W |           |         |            |          |
|   20W |           |         |            |          |
|   30W |           |         |            |          |
|   40W |           |         |            |          |
|   50W |           |         |            |          |
|   60W |           |         |            |          | -->

##### A.2.2 Forced
- Input & Output
<br>The image displays two output scopes for Forced Coagulation operations at the power stage output:
  - Left Scope:<br>This represents the output for the Forced Coagulation operation at the controller. It illustrates the waveform characteristics and performance metrics associated with the coag forced process, highlighting its unique features.
  - Right Scope:<br>This represents the output for the Forced Coagulation operation at the power stage. It showcases the waveform details and performance metrics related to the coag forced process, allowing for a comparative analysis between the two stages.

> [!NOTE]
> The oscilloscope setup uses a passive probe with a 10x attenuation factor and a voltage divider of 1/10, resulting in a total measurement factor of 100.

<p align="center">
  <img src="pic/Reverse%20Engineering/scope%20-%20generator%20output%20-%20new/monopolar/coag/forced/monopolar-coag-forced-io.png" alt="coag-forced">
</p>

Forced Coag Modulation Frequency:_
```
T = 52.2µs

f = 1 ÷ 52.2µs
f = 19.2kHz
```

Forced Coag Duty:_
| Power (W) | Duty (%)  |
| --------: | --------: |
|        10 |       3.1 |
|        20 |       5.7 |
|        30 |       7.7 |
|        40 |       8.8 |
|        50 |      10.3 |
|        60 |      11.5 |

_Peak Voltage (Vp) and Current (I):_
<br>The Vp is calculated by taking the vertical division setting on the oscilloscope and multiplying it by 100 (total measurement factor), along with the vertical scale of 1V per division (1V/div).

> [!NOTE]
> In this analysis, the peak voltage (Vp) is calculated using a simple method that involves measuring the vertical divisions of the peak-to-peak voltage (Vpp) on the oscilloscope. To begin, one observes the oscilloscope display and counts the total number of vertical divisions that the waveform spans from the maximum positive peak to the maximum negative peak, which provides the peak-to-peak voltage (Vpp). The peak voltage (Vp) is then determined by dividing the Vpp by two, expressed mathematically as `Vp = Vpp ÷ 2`.<br><br>While this method is straightforward and convenient, it is important to recognize its limitations, particularly when dealing with asymmetric signals. In an asymmetric waveform, the positive and negative peaks may not be equal in magnitude. Consequently, simply dividing the Vpp by two assumes that the waveform is symmetrical around the zero voltage line, which is often not the case. This approach can lead to significant errors in the calculated peak voltage, as it does not account for the actual heights of the individual peaks. For instance, if the positive peak is much higher than the negative peak, the calculated Vp will not accurately reflect the true maximum voltage deviation from zero.

<!-- | Power | Vp Spray  | I Spray | Vp  Forced | I Forced |
| ----: | --------: | ------: | ---------: | -------: |
|    5W |           |         |            |          |
|   10W |           |         |            |          |
|   20W |           |         |            |          |
|   30W |           |         |            |          |
|   40W |           |         |            |          |
|   50W |           |         |            |          |
|   60W |           |         |            |          | -->

### B. Bipolar Standard Coag
- Input
- Output
<br>The image illustrates the output scope for the Bipolar Standard Coagulation operation at the power stage output. It provides a detailed view of the waveform characteristics and performance metrics associated with the bipolar coagulation process, highlighting the key features and behavior of the signal during this operation.

> [!NOTE]
> The oscilloscope setup uses a passive probe with a 10x attenuation factor and a voltage divider of 1/10, resulting in a total measurement factor of 100.

<p align="center">
  <img src="pic/Reverse%20Engineering/scope%20-%20generator%20output/bipolar%20coag%20standard.png" alt="coag-standard">
</p>

_Peak Voltage (Vp) and Current (I):_
<br>The Vp is calculated by taking the vertical division setting on the oscilloscope and multiplying it by 100 (total measurement factor), along with the vertical scale of 500mV per division (500mV/div).

| Power | Vp     | I      |
| ----: | -----: | -----: |
|    5W |        |        |
|   10W |        |        |
|   20W |        |        |
|   30W |        |        |
|   40W |        |        |
|   50W |        |        |
|   60W |        |        |

## Electronic Design
<p align="center">
  <img src="pic/ESU-block-diagram.png" alt="esu-block-diagram">
</p>

<!-- 0: drain mosfet
1: output 555
2: output T (ref J3-4)
3: output T (ref J3-4)

CTL-18 | btn coag | active LOW
CTL-19 | btn cut  | active LOW -->

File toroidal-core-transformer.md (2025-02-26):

Building a small toroidal core transformer to step down a 12V sine wave input to an 8V sine wave output involves several design considerations, including core selection, winding calculations, and safety precautions. Below is a detailed guide to help we design and build our transformer.

## 1. Understanding Transformer Basics
A transformer operates on the principle of electromagnetic induction. The voltage ratio between the primary (input) and secondary (output) windings is proportional to the number of turns in each winding:
```math
\frac{V_p}{V_s} = \frac{N_p}{N_s}
```

Where:
- $V_p$ = Primary voltage (12V)
- $V_s$ = Secondary voltage (8V)
- $N_p$ = Number of turns in the primary winding
- $N_s$ = Number of turns in the secondary winding

## 2. Voltage Ratio Calculation
To find the turns ratio, we can rearrange the formula:
```math
\frac{N_p}{N_s} = \frac{V_p}{V_s} = \frac{12V}{8V} = 1.5
```
This means that for every 1.5 turns on the primary, there should be 1 turn on the secondary.

## 3. Core Selection
For high-frequency applications like 81.3 kHz, a suitable core material is essential. Ferrite cores are typically used for high-frequency transformers due to their low losses at high frequencies.
- Core Material:<br>Ferrite is preferred for high-frequency applications.
- Core Size:<br>The core size will depend on the power rating of the transformer. For small applications, a core with a cross-sectional area of around 1-2 cm² is often sufficient.

## 4. Winding Calculations
To determine the number of turns for each winding, we need to know the core's magnetic properties, specifically the maximum flux density $\(B_{max}\)$ and the core's cross-sectional area $\(A\)$.

### 4.a. Calculate the Maximum Flux $\( \Phi_{max} \)$
```math
\Phi_{max} = \frac{V_p}{4.44 • f • N_p}
```
Where:
- $f$ = Frequency of the sine wave (81.3kHz)
- $N_p$ = Number of turns in the primary winding (to be determined)

### 4.b. Determine $\(B_{max}\)$
- For typical ferrite cores, $B_{max}$ is around 0.3T to 0.5T.
- For silicon steel, it can be around 1.5T.

### 4.c. Calculate the Number of Turns
Rearranging the formula gives:
```math
N_p = \frac{V_p}{4.44 • f • \Phi_{max}}
```

## 5. Calculation
Asuming:
- $V_p = 12V$
- $V_s = 8V$
- $f = 81.3kHz = 81300Hz$
- $B_{max} = 0.3T$
- Core cross-sectional area $A = \frac{OD - ID}{2} • H = \frac{36 \text{ mm} - 22 \text{ mm}}{2} • 15 \text{ mm} = 105 \text{ mm}^2 = 105 \times 10^{-6} \text{ m}^2$

### 5.a. Calculate Maximum Flux
```math
\Phi_{max} = B_{max} • A = 0.3 \, T • 105 \times 10^{-6} \, m^2 = 3.15 \times 10^{-5} \, Wb
```

### 5.b. Calculate Number of Turns:
```math
N_p = \frac{12V}{4.44 • 81300 Hz • 3.15 \times 10^{-5} \, Wb} \approx  1.05 \text{ turns}
```

### 5.c. Calculate Secondary Turns:
```math
N_s = \frac{N_p}{1.5} \approx \frac{1.05}{1.5} \approx 0.7 \text{ turns}
```

### 5.d. Multiply Turns by 10:
- Primary $N_p = 1.05 • 10 ≈ 11 { turns}$
- Secondary $N_s = 0.7 • 10 ≈ 7 { turns}$
This is much more practical because:
- The turns ratio remains 11:7 (approximately 1.5:1)
- The number of turns is feasible to wind
- Still maintains the voltage ratio (12V:8V)
- Works with the given core size (OD=36mm, ID=22mm, H=15mm)
- Suitable for high frequency operation (81.3kHz)

### 5.e. Notes
When we multiply the number of turns by 10 (changing from Np=1.05 to Np=10.5 ≈ 11 turns), several important effects occur:
#### Inductance Effect
- Inductance is proportional to the square of the number of turns (L ∝ N²)
- When N increases by 10×, inductance increases by 100×
- This means the transformer's ability to store magnetic energy increases significantly
#### Voltage/Current Relationship
- The voltage ratio remains the same (12V:8V) because we multiply both primary and secondary turns by the same factor
- However, the current handling capacity changes due to the increased number of turns:
  - More turns = longer wire = higher resistance
  - This can affect efficiency and heat generation
#### Core Saturation
- The magnetic flux density (B) is inversely proportional to the number of turns
- With 10× more turns, the flux density decreases by 10×
- This reduces the risk of core saturation
- Makes the transformer more stable and linear in operation
#### Practical Benefits
- Makes the transformer physically buildable (1.05 turns is not practical)
- Provides better coupling between primary and secondary
- Improves regulation and efficiency
- Reduces core losses due to lower flux density
5. Trade-offs
- Increased copper losses due to longer wire length
- Higher parasitic capacitance between turns
- The multiplication by 10 transforms a theoretical calculation into a practical design while maintaining the basic voltage transformation ratio.

## 6. Winding the Transformer
### 6.a. MPL Calculation
This is the Mean Path Length that the magnetic flux follows through the core. 
```math
\text{MPL} = 2(\frac{36 - 22}{2} + 15) = 2(7 + 15) = 2(22) = 44 \text{ mm}
```

### 6.b. Wire Length Calculations
- Primary Winding:
  - Turns: 11
  - Length needed: 11 × 44mm = 484mm ≈ 0.5 meters
  - Add 20% for leads and connections: 0.6 meters
- Secondary Windings:
  - Turns: 7
  - Length needed: 7 × 44mm = 308mm ≈ 0.31 meters
  - Add 20% for leads and connections: 0.37 meters

### 6.c Wire Specifications
- Primary: AWG 22 (0.644mm diameter)
  - Current capacity: ~1.1A
  - Diameter with insulation: ~0.7mm
- Secondary: AWG 20 (0.812mm diameter)
  - Current capacity: ~1.5A
  - Diameter with insulation: ~0.9mm

### 6.d. Final Specifications
```
Primary Winding:
- Turns: 11
- Wire: AWG 22 (0.644mm)
- Length: 0.6 meters (including leads)
- Current: 0.83A max

Secondary Winding:
- Turns: 7
- Wire: AWG 20 (0.812mm)
- Length: 0.37 meters (including leads)
- Current: 1.25A max

Core Dimensions:
- OD: 36mm
- ID: 22mm
- Height: 15mm
- MPL: 44mm
```

## 7. Connections
- Connect the primary winding to our 12V AC source.
- Connect the secondary winding to our load, which will receive the 8V AC output.

## 8. Testing the Transformer
- Use a multimeter to check the output voltage before connecting a load.
- Ensure that the transformer does not overheat during operation.

## 9. Safety Precautions
- Ensure proper insulation of the windings to prevent short circuits.
- Use a fuse or circuit breaker on the primary side to protect against overload.
- Be cautious when working with AC voltages.

By following these steps, we can design and build a small toroidal core transformer to step down a 12V sine wave input to an 8V sine wave output. Ensure to consider the core material, winding techniques, and safety precautions during the construction process.

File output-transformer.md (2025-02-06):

# Output Transformer
## Monopolar
→ active
  → electrode
  → cut
  → coag
→ dispersive
  → return electrode (neutral)
  → return electrode (neutral)

## Bipolar
→ active → electrode
→ active → electrode

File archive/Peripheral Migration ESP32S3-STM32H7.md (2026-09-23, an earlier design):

VAR             ESP32S3     PHR                                     STM32H7     PHR
SENS_CUT        IO.4        Digital Input                           PA0         EXTI Line 0 (Pull-Up)
SENS_COAG       IO.5        Digital Input                           PA1         EXTI Line 1 (Pull-Up)
OPTO            IO.6        Digital Input                           PA2         EXTI Line 2 (Pull-Up)
REM             IO.7                                                PA3         ADC1_INP15 (Single-ended)
MSD2            IO.15       Digital Input                           PB0         GPIO Input (Pull-Up)
MSD1            IO.16       Digital Input                           PB1         GPIO Input (Pull-Up)
CTL_RLY         IO.8        Digital Output                          PC4         GPIO Output (Push-Pull)
PWM_0           IO.1        RMT_TX_CHANNEL_0 80MHz (clk_div=1)      PA8         HRTIM1_CHA1
PWM_1           IO.2        RMT_TX_CHANNEL_1 20MHz (clk_div=4)      PA9         HRTIM1_CHB1
PWM_EN          IO.38       Digital Output                          PD2	        GPIO Output (Push-Pull)
CTL_BUZZ        IO.36       LEDC                                    PB8         TIM4_CH3

==========================================================================================================

PA0     22      SENS_CUT
PA1     23      SENS_COAG
PA2     24      MSD1
PA3     25      MSD2
PA4     28      OPTO
PA5     29      CTL_RLY1
PA6     30      CTL_RLY2
PA7     31      PWM_EN

PC6     63      PWM0            HRTIM_CHA1
PA8     65      PWM1            HRTIM_CHB1

PC2_C   17      GND
PC3_C   18      REM

PD11    58      QSPI_BK1_IO0
PD12    59      QSPI_BK1_IO1
PD13    60      QSPI_BK1_IO3
PE2     1       QSPI_BK1_IO2
PB2     36      QSPI_CLK
PB6     92      QSPI_BK1_NCS

PD6     87      FLASH_CS
PD7     88      FLASH_DI        SPI1_MOSI
PB3     89      FLASH_CLK       SPI1_SCK
PB4     90      FLASH_DO        SPI1_MISO

Pin assignment [In Review]
PWM0            OK
PWM1            OK
FLASH QSPI      OK
FLASH SPI       OK

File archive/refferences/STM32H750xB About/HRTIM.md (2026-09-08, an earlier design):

# Datasheet - production data STM32H750VB STM32H750ZB STM32H750IB STM32H750XB
## 3 Functional Overview
### 3.29 Timers and watchdogs
#### 3.29.1 High-resolution timer (HRTIM1)

The high-resolution timer (HRTIM1) allows generating digital signals with high-accuracy timings, such as PWM or phase-shifted pulses.

It consists of 6 timers, 1 master and 5 slaves, totaling 10 high-resolution outputs, which can be coupled by pairs for deadtime insertion. It also features 5 fault inputs for protection purposes and 10 inputs to handle external events such as current limitation, zero voltage or zero current switching.

The HRTIM1 timer is made of a digital kernel clocked at 480 MHz The high-resolution is available on the 10 outputs in all operating modes: variable duty cycle, variable frequency, and constant ON time.

The slave timers can be combined to control multiswitch complex converters or operate independently to manage multiple independent converters.

The waveforms are defined by a combination of user-defined timings and external events such as analog or digital feedbacks signals.

HRTIM1 timer includes options for blanking and filtering out spurious events or faults. It also offers specific modes and features to offload the CPU: DMA requests, Burst mode controller, Push-pull and Resonant mode.

It supports many topologies including LLC, Full bridge phase shifted, buck or boost converters, either in voltage or current mode, as well as lighting application (fluorescent or LED). It can also be used as a general purpose timer, for instance to achieve high-resolution PWM-emulated DAC.

# RM0433
## 37 High-Resolution Timer (HRTIM)
### 37.1 Introduction
The high-resolution timer can generate up to 10 digital signals with highly accurate timings. It is primarily intended to drive power conversion systems such as switch mode power supplies or lighting systems, but can be of general purpose usage, whenever a very fine timing resolution is expected.

Its modular architecture allows to generate either independent or coupled waveforms. The wave-shape is defined by self-contained timings (using counters and compare units) and a broad range of external events, such as analog or digital feedbacks and synchronization signals. This allows to produce a large variety of control signal (PWM, phase-shifted, constant Ton,...) and address most of conversion topologies.

For control and monitoring purposes, the timer has also timing measure capabilities and links to built-in ADC and DAC converters. Last, it features light-load management mode and is able to handle various fault schemes for safe shut-down purposes.

### 37.2 Main features
-   Multiple timing units
    - Full-resolution available on all outputs, possibility to adjust duty-cycle, frequency and pulse width in triggered one-pulse mode
    - 6 16-bit timing units (each one with an independent counter and 4 compare units)
    - 10 outputs that can be controlled by any timing unit, up to 32 set/reset sources per channel
    - Modular architecture to address either multiple independent converters with 1 or 2 switches or few large multi-switch topologies
-   Up to 10 external events, available for any timing unit
    - Programmable polarity and edge sensitivity
    - 5 events with a fast asynchronous mode
    - 5 events with a programmable digital filter
    - Spurious events filtering with blanking and windowing modes
-   Multiple links to built-in analog peripherals
    - 4 triggers to ADC converters
    - 3 triggers to DAC converters
    - 3 comparators for analog signal conditioning
-   Versatile protection scheme
    - 5 fault inputs can be combined and associated to any timing unit
    - Programmable polarity, edge sensitivity, and programmable digital filter
    - dedicated delayed protections for resonant converters
-   Multiple HRTIM instances can be synchronized with external synchronization inputs/outputs
-   Versatile output stage
    - Full-resolution Deadtime insertion
    - Programmable output polarity
    - Chopper mode
-   Burst mode controller to handle light-load operation synchronously on multiple converters
-   7 interrupt vectors, each one with up to 14 sources
-   6 DMA requests with up to 14 sources, with a burst mode for multiple registers update

### 37.3 Functional description
#### 37.3.1 General description
The HRTIM can be partitioned into several sub entities:
-   The master timer
-   The timing units (Timer A to Timer E)
-   The output stage
-   The burst mode controller
-   An external event and fault signal conditioning logic that is shared by all timers
-   The system interface

The master timer is based on a 16-bit up counter. It can set/reset any of the 10 outputs via 4 compare units and it provides synchronization signals to the 5 timer units. Its main purpose is to have the timer units controlled by a unique source. An interleaved buck converter is a typical application example where the master timer manages the phase-shifts between the multiple units.

The timer units are working either independently or coupled with the other timers including the master timer. Each timer contains the controls for two outputs. The outputs set/reset events are triggered either by the timing units compare registers or by events coming from the master timer, from the other timers or from external events.

The output stage has several duties
-   Addition of deadtime when the 2 outputs are configured in complementary PWM mode
-   Addition of a carrier frequency on top of the modulating signal
-   Management of fault events, by asynchronously asserting the outputs to a predefined safe level

The burst mode controller can take over the control of one or multiple timers in case of light- load operation. The burst length and period can be programmed, as well as the idle state of the outputs.

The external event and fault signal conditioning logic includes:
-   The input selection MUXes (for instance for selecting a digital input or an on-chip source for a given external event channel)
-   Polarity and edge-sensitivity programming
-   Digital filtering (for 5 channels out of 10)

The system interface allows the HRTIM to interact with the rest of the MCU:
-   Interrupt requests to the CPU
-   DMA controller for automatic accesses to/from the memories, including an HRTIM specific burst mode
-   Triggers for the ADC and DAC converters

The HRTIM registers are split into 7 groups:
-   Master timer registers
-   Timer A to Timer E registers
-   Common registers for features shared by all timer units

Note: As a writing convention, references to the 5 timing units in the text and in registers are generalized using the “x” letter, where x can be any value from A to E.

#### 37.3.2 HRTIM pins and internal signals
The table here below summarizes the HRTIM inputs and outputs, both on-chip and off-chip.

<table>
  <tr>
    <th>Signal name</th>
    <th>Signal type</th>
    <th>Description</th>
  </tr>
  <tr>
    <td>
        HRTIM_CHA1,<br>HRTIM_CHA2,<br>HRTIM_CHB1,<br>HRTIM_CHB2,<br>HRTIM_CHC1,<br>HRTIM_CHC2,<br>HRTIM_CHD1,<br>HRTIM_CHD2,<br>HRTIM_CHE1,<br>HRTIM_CHE2
    </td>
    <td>Output</td>
    <td>Main HRTIM timer outputs. They can be coupled by pairs (HRTIM_CHx1 & HRTIM_CHx2) with deadtime insertion or work independently.</td>
  </tr>
  <tr>
    <td>HRTIM_FLT[5:1],<br>hrtim_in_flt[5:1]</td>
    <td>Digital input</td>
    <td>Fault inputs: immediately disable the HRTIM outputs when asserted (5 on-chip inputs and 5 off-chip HRTIM_FLTx inputs).</td>
  </tr>
  <tr>
    <td>hrtim_sys_flt</td>
    <td>Digital input</td>
    <td>System fault gathering MCU internal fault events (Clock security system, SRAM parity error, Cortex®-M7 lockup (HardFault), PVD output).</td>
  </tr>
  <tr>
    <td>hrtim_in_sync[3:1]</td>
    <td>Digital Input</td>
    <td>
        <p>Synchronization inputs to synchronize the whole HRTIM with other internal or external timer resources:</p>
        <ul>
            <li>hrtim_in_sync1: reserved</li>
            <li>hrtim_in_sync2: the source is a regular TIMx timer (via on-chip interconnect)</li>
            <li>hrtim_in_sync3: the source is an external HRTIM (via the HRTIM_SCIN input pins)</li>
        </ul>
    </td>
  </tr>
  <tr>
    <td>hrtim_out_sync[2:1]</td>
    <td>Digital&nbsp;output</td>
    <td>
        <p>The purpose of this output is to cascade or synchronize several HRTIM instances, either on-chip or off-chip:</p>
        <ul>
            <li>hrtim_out_sync1: reserved</li>
            <li>hrtim_out_sync2: the destination is an off-chip HRTIM or peripheral (via HRTIM_SCOUT output pins)</li>
        </ul>
    </td>
  </tr>
  <tr>
    <td>
        hrtim_evt1[4:1]<br>hrtim_evt2[4:1]<br>hrtim_evt3[4:1]<br>hrtim_evt4[4:1]<br>hrtim_evt5[4:1]<br>hrtim_evt6[4:1]<br>hrtim_evt7[4:1]<br>hrtim_evt8[4:1]<br>hrtim_evt9[4:1]<br>hrtim_evt10[4:1]
    </td>
    <td>Digital input</td>
    <td>
        External events. Each of the 10 events can be selected among 4 sources, either on-chip (from other built-in peripherals: comparator, ADC analog watchdog, TIMx timers, trigger outputs) or off-chip (HRTIM_EEVx input pins)
    </td>
  </tr>
  <tr>
    <td>hrtim_upd_en[3:1]</td>
    <td>Digital input</td>
    <td>HRTIM register update enable inputs (on-chip interconnect) trigger the transfer from shadow to active registers</td>
  </tr>

  <tr>
    <td>hrtim_bm_trg</td>
    <td>Digital input</td>
    <td>Burst mode trigger event (on-chip interconnect)</td>
  </tr>
  <tr>
    <td>hrtim_bm_ck[4:1]</td>
    <td>Digital input</td>
    <td>Burst mode clock (on-chip interconnect)</td>
  </tr>
  <tr>
    <td>hrtim_adc_trg[4:1]</td>
    <td>Digital output</td>
    <td>ADC start of conversion triggers</td>
  </tr>
  <tr>
    <td>hrtim_dac_trg[3:1]</td>
    <td>Digital output</td>
    <td>DAC conversion update triggers</td>
  </tr>
  <tr>
    <td>hrtim_mst_it[7:1]</td>
    <td>Digital output</td>
    <td>Interrupt requests</td>
  </tr>
  <tr>
    <td>hrtim_dma[6:1]</td>
    <td>Digital output</td>
    <td>DMA requests</td>
  </tr>
  <tr>
    <td>hrtim_pclk</td>
    <td>Digital input</td>
    <td>APB clock</td>
  </tr>
  <tr>
    <td>hrtim_ker_ck</td>
    <td>Digital input</td>
    <td>HRTIM&nbsp;kernel&nbsp;clock&nbsp;(hereafter&nbsp;mentioned&nbsp;as&nbsp;f<sub>HRTIM)</sub></td>
  </tr>
</table>

#### 37.3.3 HRTIM pins and internal signals
The HRTIM must be supplied by the tHRTIM system clock to offer a full resolution. All clocks present in the HRTIM are derived from this reference clock.

##### Definition of terms
<table>
    <tr>
        <td>f<sub>HRTIM</sub></td>
        <td>
            main HRTIM clock (hrtim_ker_ck). All subsequent clocks are derived and synchronous with this source.
        </td>
    </tr>
    <tr>
        <td>f<sub>DTG</sub></td>
        <td>
            deadtime generator clock. For convenience, only the tDTG period (tDTG = 1/fDTG) is used in this document.
        </td>
    </tr> 
    <tr>
        <td>f<sub>CHPFRQ</sub></td>
        <td>chopper stage clock source.</td>
    </tr>
    <tr>
        <td>f<sub>1STPW</sub></td>
        <td>
            clock source defining the length of the initial pulse in chopper mode. For convenience, only the t<sub>1STPW</sub> period (t<sub>1STPW</sub> = 1/f<sub>1STPW</sub>) is used in this document.
        </td>
    </tr>
    <tr>
        <td>f<sub>BRST</sub></td>
        <td>burst mode controller counter clock.</td>
    </tr>
    <tr>
        <td>f<sub>SAMPLING</sub></td>
        <td>clock needed to sample the fault or the external events inputs.</td>
    </tr>
    <tr>
        <td>f<sub>FLTS</sub></td>
        <td>clock derived from fHRTIM which is used as a source for fSAMPLING to filter fault events.</td>
    </tr>
    <tr>
        <td>f<sub>EEVS</sub></td>
        <td>clock derived from fHRTIM which is used as a source for fSAMPLING to filter external events.</td>
    </tr>
    <tr>
        <td>f<sub>pclk</sub>(hrtim_pclk)</td>
        <td>APB bus clock, needed for register read/write accesses</td>
    </tr>
</table>

##### Timer clock and prescaler
Each timer in the HRTIM has its own individual clock prescaler, which allows you to adjust the timer resolution. (See Table 304).

<div align="center">
Table 304. Timer resolution and min. PWM frequency for fHRTIM = 400 MHz
<table>
  <tr>
    <th>CKPSC[2:0]<sup>(1)</sup></th>
    <th>Prescaling ratio</th>
    <th>f<sub>COUNTER</sub></th>
    <th>Resolution</th>
    <th>Min PWM frequency</th>
  </tr>
  <tr>
    <td align="center">101</td>
    <td align="center">1</td>
    <td align="right">400 MHz</td>
    <td align="right">2.5 ns</td>
    <td align="right">6.1 kHz</td>
  <tr>
  <tr>
    <td align="center">110</td>
    <td align="center">2</td>
    <td align="right">400/2 MHz = 200 MHz</td>
    <td align="right">5 ns</td>
    <td align="right">3.05 kHz</td>
  <tr>
  <tr>
    <td align="center">111</td>
    <td align="center">4</td>
    <td align="right">400/4 MHz = 400 MHz</td>
    <td align="right">10 ns</td>
    <td align="right">1.5 kHz</td>
  <tr>
</table>
</div>

<sup>1. CKPSC[2:0] values from 000 to 100 are reserved.</sup>

The Full-resolution is available for edge positioning, PWM period adjustment and externally
triggered pulse duration.

##### Initialization
At start-up, it is mandatory to initialize first the prescaler bitfields before writing the compare and period registers. Once the timer is enabled (MCEN or TxCEN bit set in the HRTIM_MCR register), the prescaler cannot be modified.

When multiple timers are enabled, the prescalers are synchronized with the prescaler of the timer that was started first.

> [!WARNING]
> It is possible to have different prescaling ratios in the master and TIMA..E timers only if the counter and output behavior does not depend on other timers’ information and signals. It is mandatory to configure identical prescaling ratios in these timers when one of the following events is propagated from one timing unit (or master timer) to another: output set/reset event, counter reset event, update event, external event filter or capture triggers. Prescaler factors not equal will yield to unpredictable results.

##### Deadtime generator clock
The deadtime prescaler is supplied by f<sub>HRTIM</sub> / 8 / 2<sup>(DTPRSC[2:0])</sup>, programmed with
DTPRSC[2:0] bits in the HRTIM_DTxR register.

t<sub>DTG</sub> ranges from 2.5 ns to 20 ns for f<sub>HRTIM</sub> = 400 MHz.

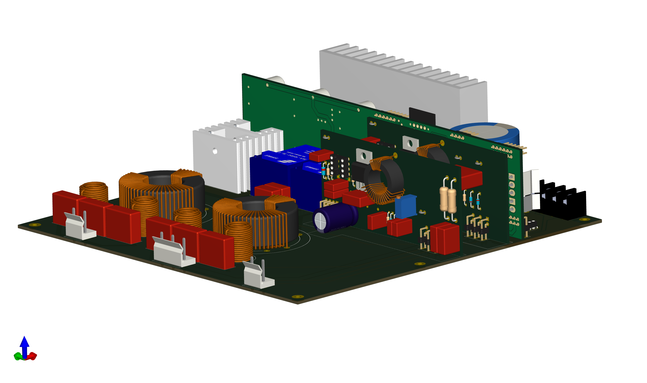
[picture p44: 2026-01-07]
hardware/PS-5.2/PS-5.2.png

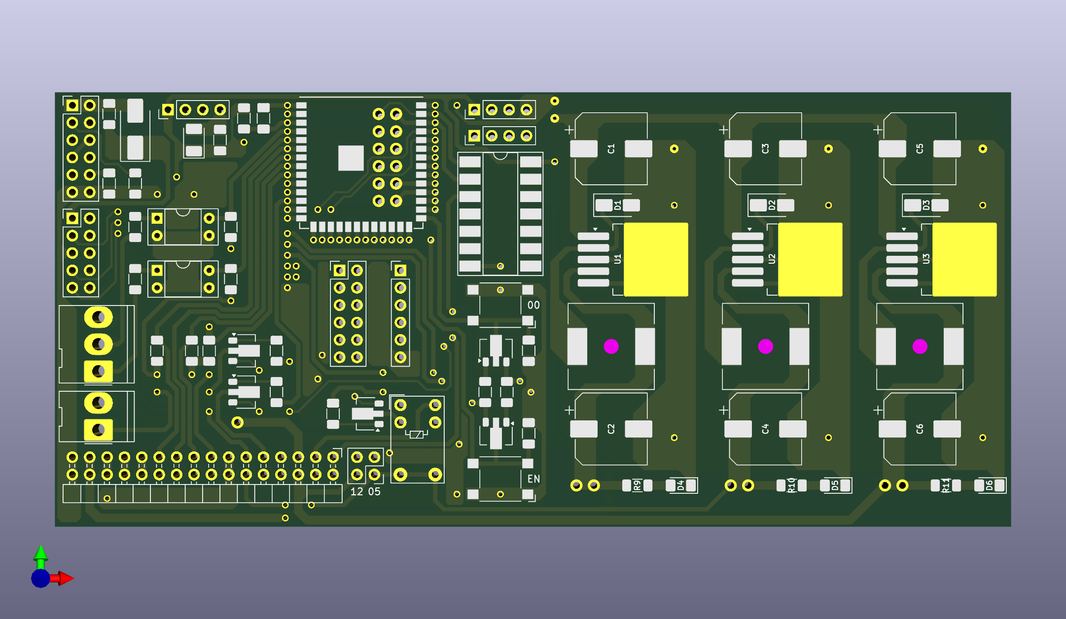
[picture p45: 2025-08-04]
hardware/CTL-6.1/CTL-6.1.png

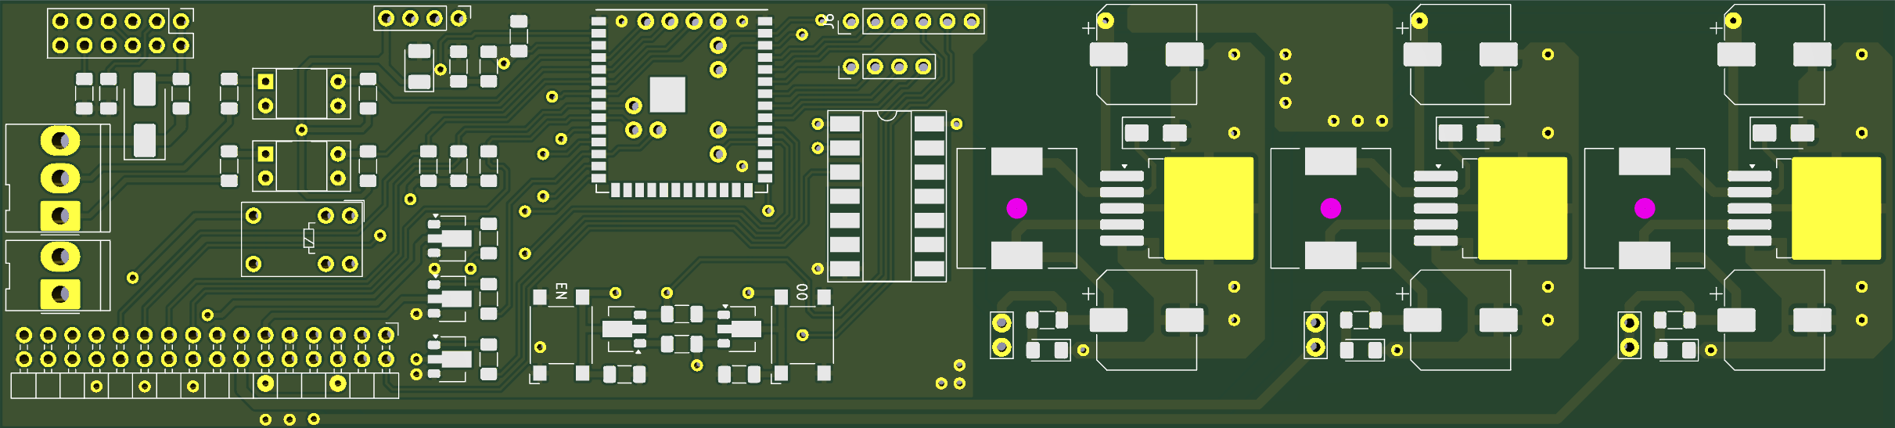
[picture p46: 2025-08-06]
hardware/CTL-3.0/CTL-3.0-Top-SilkScreen.png

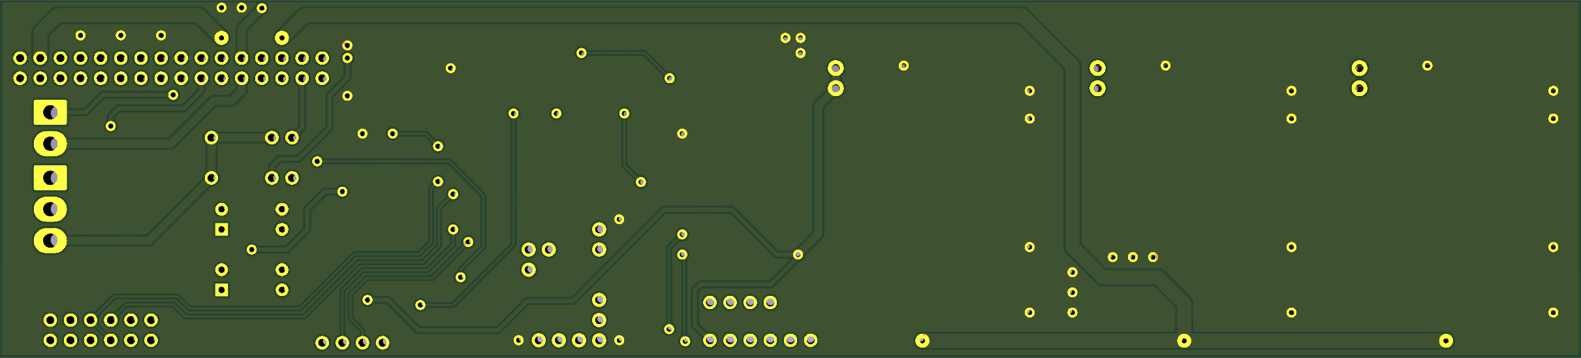
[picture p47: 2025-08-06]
hardware/CTL-3.0/CTL-3.0-Bottom-SilkScreen.png

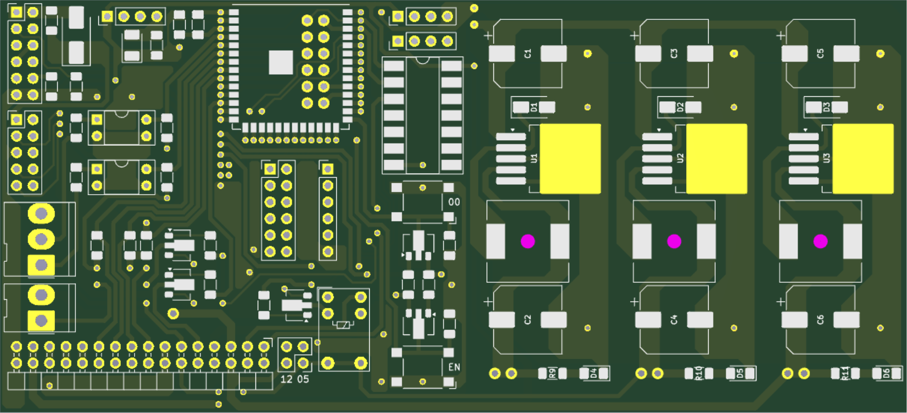
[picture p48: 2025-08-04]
hardware/CTL-1.2/CTL-1.2-TopSilkscreen.png

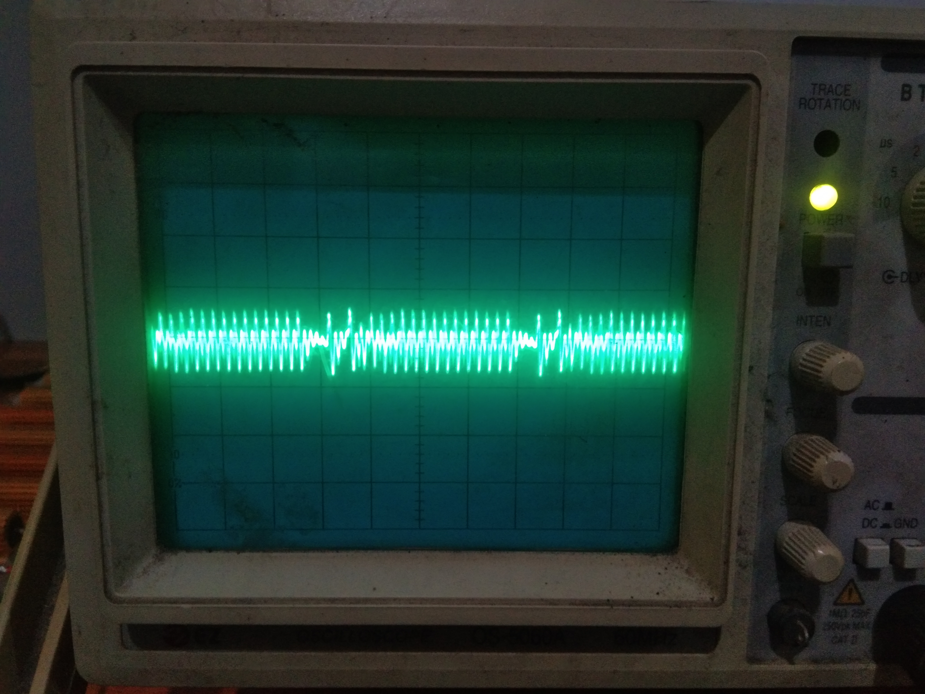
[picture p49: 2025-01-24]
pic/Reverse Engineering/scope - generator output/monopolar cut blend1 [1V per DIV] [10µs per DIV] 5W.jpg

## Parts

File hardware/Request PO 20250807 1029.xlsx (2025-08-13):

Supplier |  | : JayaTronik Smg (https://www.tokopedia.com/smgjayatronik)
# |  | Item | Qty | Harga Satuan (Rp) | Harga Total (Rp) | https://github.com/mekanii/ESU/invitations
1 | https://www.tokopedia.com/smgjayatronik/socket-ic-14-pin-socket-14-pin | Socket IC 14 Pin (https://www.tokopedia.com/smgjayatronik/socket-ic-14-pin-socket-14-pin) | 1 | 660 | 660
2 | https://www.tokopedia.com/smgjayatronik/cd4071be-cd4071-ic-4071-pdip-14-1729801493127333767 | 4071 (https://www.tokopedia.com/smgjayatronik/cd4071be-cd4071-ic-4071-pdip-14-1729801493127333767) | 1 | 7700 | 7700
3 | https://www.tokopedia.com/smgjayatronik/cd4071bcm-cd4071-smd-ic-4071 | 4071 SMD (https://www.tokopedia.com/smgjayatronik/cd4071bcm-cd4071-smd-ic-4071) | 2 | 11000 | 22000
4 | https://www.tokopedia.com/smgjayatronik/pcb-ic-titik-matrix-tw-19-5-x-9-cm | PCB Matrix TW 19.5 x 9 cm (https://www.tokopedia.com/smgjayatronik/pcb-ic-titik-matrix-tw-19-5-x-9-cm) | 2 | 7700 | 15400
 |  |  |  | Sub Total | 45760
 |  |  |  | Biaya Kirim | 5000
 |  |  |  | Total | 50760
Supplier |  | : Central Electronics (https://www.tokopedia.com/celectro)
# |  | Item | Qty | Harga Satuan (Rp) | Harga Total (Rp)
1 | https://www.tokopedia.com/celectro/relay-g5v-1-5vdc | RELAY G5V-1 5VDC (https://www.tokopedia.com/celectro/relay-g5v-1-5vdc) | 4 | 12900 | 51600
 |  |  |  | Sub Total | 51600
 |  |  |  | Biaya Kirim | 17000
 |  |  |  | Total | 68600
Supplier |  | : mitrus (https://www.tokopedia.com/mitrus-539)
# |  | Item | Qty | Harga Satuan (Rp) | Harga Total (Rp)
1 | https://www.tokopedia.com/mitrus-539/kawat-tembaga-email-0-20-mm-enamel-wire-cooper-gulung-dinamo-ilmail-1 | Enameled Copper Wire 0.2mm (https://www.tokopedia.com/celectro/relay-g5v-1-5vdc) | 5 | 26500 | 132500
 |  |  |  | Sub Total | 132500
 |  |  |  | Biaya Kirim | 14200
 |  |  |  | Total | 146700
Supplier |  | : Putra Niaga Elektronik (https://www.tokopedia.com/putraniagabdg)
# |  | Item | Qty | Harga Satuan (Rp) | Harga Total (Rp)
1 | https://www.tokopedia.com/putraniagabdg/tantalum-smd-22uf-10v-kapasitor-22-uf-kode-226-dimensi-3528 | Capacitor Tantalum 22µF 10V 3528 (https://www.tokopedia.com/putraniagabdg/tantalum-smd-22uf-10v-kapasitor-22-uf-kode-226-dimensi-3528) | 4 | 2500 | 10000
2 | https://www.tokopedia.com/putraniagabdg/push-on-4p-mini-pcb-tact-switch-tombol-reset-4pin-tinggi-4-3mm | Tactile switch 6x6 H 4.3 mm (https://www.tokopedia.com/putraniagabdg/push-on-4p-mini-pcb-tact-switch-tombol-reset-4pin-tinggi-4-3mm) | 4 | 500 | 2000
3 | https://www.tokopedia.com/putraniagabdg/pc817-optocoupler-pc-817-dip-4pin-pc817-1-high-quality | Optocoupler PC817 (https://www.tokopedia.com/putraniagabdg/pc817-optocoupler-pc-817-dip-4pin-pc817-1-high-quality) | 10 | 1500 | 15000
4 | https://www.tokopedia.com/putraniagabdg/1-set-konektor-header-5-pin-3-96mm-lock-5p-3-96-mm-male-female-5pin-1729814123560600872 | (1 Set) Connector JST 5P Pitch 3.96 mm (https://www.tokopedia.com/putraniagabdg/1-set-konektor-header-5-pin-3-96mm-lock-5p-3-96-mm-male-female-5pin-1729814123560600872) | 6 | 7250 | 43500
5 | https://www.tokopedia.com/putraniagabdg/1-set-konektor-header-3-pin-3-96mm-lock-3p-3-96-mm-male-female-3pin | (1 Set) Connector JST 3P Pitch 3.96 mm (https://www.tokopedia.com/putraniagabdg/1-set-konektor-header-3-pin-3-96mm-lock-3p-3-96-mm-male-female-3pin) | 7 | 4500 | 31500
6 | https://www.tokopedia.com/putraniagabdg/1-set-konektor-header-2-pin-3-96mm-lock-2p-3-96-mm-male-female-2pin | (1 Set) Connector JST 2P Pitch 3.96 mm (https://www.tokopedia.com/putraniagabdg/1-set-konektor-header-2-pin-3-96mm-lock-2p-3-96-mm-male-female-2pin) | 1 | 3000 | 3000
7 | https://www.tokopedia.com/putraniagabdg/header-male-baris-1x40-pin-2-54mm-1-x-40-fcp-1x40p-hitam-1729809669501388072 | Header Male 1x40 Pitch 2.54 mm (https://www.tokopedia.com/putraniagabdg/header-male-baris-1x40-pin-2-54mm-1-x-40-fcp-1x40p-hitam-1729809669501388072) | 1 | 1000 | 1000
8 | https://www.tokopedia.com/putraniagabdg/header-male-baris-2x40-pin-2-54mm-2-x-40-fcp-2x40p-hitam | Header Male 2x40 Pitch 2.54 mm (https://www.tokopedia.com/putraniagabdg/header-male-baris-2x40-pin-2-54mm-2-x-40-fcp-2x40p-hitam) | 1 | 2000 | 2000
9 | https://www.tokopedia.com/putraniagabdg/header-male-siku-2x40-l-2-54mm-2-x-40-fcp-baris-2x40p-belok-r-a-1729824156178613544 | Header Male 2x40 Pitch 2.54 mm Right Angle (https://www.tokopedia.com/putraniagabdg/header-male-siku-2x40-l-2-54mm-2-x-40-fcp-baris-2x40p-belok-r-a-1729824156178613544) | 1 | 3000 | 3000
10 | https://www.tokopedia.com/putraniagabdg/header-female-baris-2x40-pin-2-54mm-2-x-20-fcp-2x40p-hitam | Header Female 2x40 Pitch 2.54 mm (https://www.tokopedia.com/putraniagabdg/header-female-baris-2x40-pin-2-54mm-2-x-20-fcp-2x40p-hitam) | 1 | 5000 | 5000
11 | https://www.tokopedia.com/putraniagabdg/header-female-2x20-pin-kaki-panjang-pitch-2-54mm-20x2-double-row-long-pin-2x20p | Header Female 2x20 Pitch 2.54 mm Long Pin (https://www.tokopedia.com/putraniagabdg/header-female-2x20-pin-kaki-panjang-pitch-2-54mm-20x2-double-row-long-pin-2x20p) | 2 | 9500 | 19000
 |  |  |  | Sub Total | 135000
 |  |  |  | Biaya Kirim | 17000
 |  |  |  | Total | 152000
Supplier |  | : Lisu Instruments (https://www.tokopedia.com/lisuinstrument)
# |  | Item | Qty | Harga Satuan (Rp) | Harga Total (Rp)
1 | https://www.tokopedia.com/lisuinstrument/ss36b-60v-3a-schottky-barrier-rectifier-ss36-smb-ctk-electronics | Schottky SS36 SMB (https://www.tokopedia.com/lisuinstrument/ss36b-60v-3a-schottky-barrier-rectifier-ss36-smb-ctk-electronics) | 6 | 699 | 4194
2 | https://www.tokopedia.com/lisuinstrument/bcx56-npn-80v-1a-500mw-hfe-100-250-transistor-bjt-sot-89-3-cj-original | Transistor BCX56 SOT-89-3 (https://www.tokopedia.com/lisuinstrument/bcx56-npn-80v-1a-500mw-hfe-100-250-transistor-bjt-sot-89-3-cj-original) | 10 | 1399 | 13990
3 | https://www.tokopedia.com/lisuinstrument/1206-smd-led-smt-ultra-bright-berbagai-pilihan-warna-merah | LED 1206 (https://www.tokopedia.com/lisuinstrument/1206-smd-led-smt-ultra-bright-berbagai-pilihan-warna-merah) | 10 | 199 | 1990
4 | https://www.tokopedia.com/lisuinstrument/ss36a-60v-3a-schottky-diode-sma-do-214ac-ss36-hottech-original | Schottky SS36 SMA (https://www.tokopedia.com/lisuinstrument/ss36a-60v-3a-schottky-diode-sma-do-214ac-ss36-hottech-original) | 6 | 799 | 4794
5 | https://www.tokopedia.com/lisuinstrument/1uf-10-50v-x7r-1206-3216-mm-smd-capacitors-mlcc-samsung | Capacitor MLCC 1uF 50V X7R 1206 (https://www.tokopedia.com/lisuinstrument/1uf-10-50v-x7r-1206-3216-mm-smd-capacitors-mlcc-samsung) | 10 | 799 | 7990
6 | https://www.tokopedia.com/lisuinstrument/100nf-50v-x7r-10-1206-3216-mm-smd-ceramic-capacitor-cl31b104kbcnnnc | Capacitor MLCC 100nF 50V X7R 1206 (https://www.tokopedia.com/lisuinstrument/100nf-50v-x7r-10-1206-3216-mm-smd-ceramic-capacitor-cl31b104kbcnnnc) | 20 | 349 | 6980
7 | https://www.tokopedia.com/lisuinstrument/0-1206-5-smd-thick-resistor-0r-0-walsin-wr12x000ptl-1731697760176997861 | Resistor 0Ω 1206 (https://www.tokopedia.com/lisuinstrument/0-1206-5-smd-thick-resistor-0r-0-walsin-wr12x000ptl-1731697760176997861) | 10 | 1100 | 11000
8 | https://www.tokopedia.com/lisuinstrument/5-1k-1206-1-250mw-200v-100ppm-thick-film-resistors-5-1k-5k1-5101-rc1206fr-075k1l-yageo | Resistor 5.1kΩ 1206 (https://www.tokopedia.com/lisuinstrument/5-1k-1206-1-250mw-200v-100ppm-thick-film-resistors-5-1k-5k1-5101-rc1206fr-075k1l-yageo) | 25 | 149 | 3725
9 | https://www.tokopedia.com/lisuinstrument/10k-1206-1-250mw-200v-100ppm-thick-film-resistors-10k-10-1002-rc1206fr-0710kl-yageo | Resistor 10kΩ 1206 (https://www.tokopedia.com/lisuinstrument/10k-1206-1-250mw-200v-100ppm-thick-film-resistors-10k-10-1002-rc1206fr-0710kl-yageo) | 25 | 149 | 3725
 |  |  |  | Sub Total | 58388
 |  |  |  | Biaya Kirim | 0
 |  |  |  | Total | 58388
Supplier |  | : StarElektro_NEW (https://www.tokopedia.com/starelektro-1)
# |  | Item | Qty | Harga Satuan (Rp) | Harga Total (Rp)
1 | https://www.tokopedia.com/starelektro-1/lm2576s-lm2576hvs-adj-3-3-5-0-12-ic-regulator-switching-smd-to-263-5-4pcs-12volt-cfe9f | LM2576S-12 TO-263-5 (https://www.tokopedia.com/starelektro-1/lm2576s-lm2576hvs-adj-3-3-5-0-12-ic-regulator-switching-smd-to-263-5-4pcs-12volt-cfe9f) | 4 | 15000 | 60000
2 | https://www.tokopedia.com/starelektro-1/lm2576s-lm2576hvs-adj-3-3-5-0-12-ic-regulator-switching-smd-to-263-5-4pcs-5volt-61057 | LM2576S-5 TO-263-5 (https://www.tokopedia.com/starelektro-1/lm2576s-lm2576hvs-adj-3-3-5-0-12-ic-regulator-switching-smd-to-263-5-4pcs-5volt-61057) | 4 | 10000 | 40000
3 | https://www.tokopedia.com/starelektro-1/lm2576s-lm2576hvs-adj-3-3-5-0-12-ic-regulator-switching-smd-to-263-5-4pcs-3-3volt-406d1 | LM2576S-3.3 TO-263-5 (https://www.tokopedia.com/starelektro-1/lm2576s-lm2576hvs-adj-3-3-5-0-12-ic-regulator-switching-smd-to-263-5-4pcs-3-3volt-406d1) | 4 | 10000 | 40000
 |  |  |  | Sub Total | 140000
 |  |  |  | Biaya Kirim | 11000
 |  |  |  | Total | 151000
Supplier |  | : Dns Electronic (https://www.tokopedia.com/dnselectronic)
# |  | Item | Qty | Harga Satuan (Rp) | Harga Total (Rp)
1 | https://www.tokopedia.com/dnselectronic/wima-2n2-630v-mkp10 | Capacitor 2n2 630V MKP10 (https://www.tokopedia.com/dnselectronic/wima-2n2-630v-mkp10) | 1 | 15000 | 15000
2 | https://www.tokopedia.com/dnselectronic/wima-3n3-630v-mkp10 | Capacitor 3n3 630V MKP10 (https://www.tokopedia.com/dnselectronic/wima-3n3-630v-mkp10) | 2 | 15000 | 30000
3 | https://www.tokopedia.com/dnselectronic/wima-4n7-630v-mkp10 | Capacitor 4n7 630V MKP10 (https://www.tokopedia.com/dnselectronic/wima-4n7-630v-mkp10) | 3 | 15000 | 45000
 |  |  |  | Sub Total | 90000
 |  |  |  | Biaya Kirim | 0
 |  |  |  | Total | 90000
Supplier |  | : SIKIL GANGSAL (https://www.tokopedia.com/dnselectronic)
# |  | Item | Qty | Harga Satuan (Rp) | Harga Total (Rp)
1 | https://www.tokopedia.com/jayenk/solid-kapasitor-capasitor-elko-elco-smd-100uf-50v-10x10-high-quality | Solid Capacitor 100µf 50v 10x10 (https://www.tokopedia.com/jayenk/solid-kapasitor-capasitor-elko-elco-smd-100uf-50v-10x10-high-quality) | 6 | 3500 | 21000
2 | https://www.tokopedia.com/jayenk/solid-kapasitor-capasitor-elko-elco-smd-680uf-35v-680uf-vzs-size-10x10 | Solid Capacitor 680uf 35v 10x10 (https://www.tokopedia.com/jayenk/solid-kapasitor-capasitor-elko-elco-smd-680uf-35v-680uf-vzs-size-10x10) | 3 | 15000 | 45000
 |  |  |  | Sub Total | 66000
 |  |  |  | Biaya Kirim | 0
 |  |  |  | Total | 66000
Supplier |  | : Cha's Instrument (https://www.tokopedia.com/the-diy-store)
# |  | Item | Qty | Harga Satuan (Rp) | Harga Total (Rp)
1 | https://www.tokopedia.com/the-diy-store/esp32-s3-wroom-esp32-s3-wroom-1u-chip-module-8mb-psram-n16r8-16mb | ESP32-S3-WROOM-1U N16R8 (https://www.tokopedia.com/the-diy-store/esp32-s3-wroom-esp32-s3-wroom-1u-chip-module-8mb-psram-n16r8-16mb) | 1 | 114000 | 114000
 |  |  |  | Sub Total | 114000
 |  |  |  | Biaya Kirim | 21000
 |  |  |  | Total | 135000

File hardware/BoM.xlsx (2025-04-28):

Reference | Value | Footprint | Qty
C1 | 2.2nF | Capacitor_THT:C_Rect_L7.0mm_W3.5mm_P5.00mm | 2 |  | https://www.tokopedia.com/wonderland-elec/wima-fkp-2-222-2200pf-0-0022uf-100v-black-print
C2 | 10nF | Capacitor_THT:C_Rect_L7.0mm_W3.5mm_P5.00mm | 2 | 470pF | https://www.tokopedia.com/elantech/wima-10nf-103-0-01uf-j-63v-capacitor-kapasitor-elantech
 | 10nF |  | 1 |  | https://www.tokopedia.com/wonderland-elec/genuine-wima-mkp10-0-01uf-10nf-1000v-600v
C3 | 0.022uF 400V MKP | Capacitor_THT:C_Rect_L13.0mm_W5.0mm_P10.00mm_FKS3_FKP3_MKS4 | 2 |  | https://www.tokopedia.com/wonderland-elec/genuine-wima-mkp10-capacitors-0-022uf-22nf-400v-10
C4 | 22nF | Capacitor_THT:C_Rect_L7.0mm_W3.5mm_P5.00mm | 1 |  | https://www.tokopedia.com/elantech/wima-22nf-223-0-022uf-j-100v-capacitor-kapasitor-elantech
C5,C6,C8,C10 | 100nF | Capacitor_THT:C_Rect_L7.0mm_W3.5mm_P5.00mm | 5 |  | https://www.tokopedia.com/elantech/wima-100nf-104-0-1uf-j-100v-capacitor-kapasitor-elantech
C7,C9 | 470uF 50V | Capacitor_THT:CP_Radial_D10.0mm_P5.00mm | 2 |  | https://www.tokopedia.com/wonderland-elec/panasonic-fm-470uf-50v-very-low-impedance-electrolytic-capacitor-105-c
C11,C12 | 2.2nF 2000V/700 | Capacitor_THT:C_Rect_L13.0mm_W5.0mm_P10.00mm_FKS3_FKP3_MKS4 | 2 |  | https://www.tokopedia.com/smgjayatronik/capacitor-kapasitor-mkp-2000v-vdc-8-2nf-wima
D1 | byv26 | Diode_THT:D_DO-34_SOD68_P7.62mm_Horizontal | 2 |  | https://www.tokopedia.com/akaspro/byv26-byv26c-orginal
D2,D3 | 1N4148 | Diode_THT:D_DO-34_SOD68_P7.62mm_Horizontal | 2 |  | https://www.tokopedia.com/elantech/1n4148-diode-fairchild-semtech-1n-4148-substitusi-1n914-dioda-elantech-fairchild
 | HER208 | Diode_THT:D_DO-34_SOD68_P7.62mm_Horizontal | 2 |  | https://www.tokopedia.com/indo-ware/dioda-her208-her-208-do-41-diode
L1 | Isolated Transformer (Custom) | Inductor_THT:L_CommonMode_Toroid_Vertical_L30.5mm_W15.2mm_Px10.16mm_Py20.32mm_Bourns_8100 | 1
 | Isolated Transformer (Custom) | Inductor_THT:L_CommonMode_Toroid_Vertical_L30.5mm_W15.2mm_Px10.16mm_Py20.32mm_Bourns_8100 | 1
Q1 | IRF840 | Package_TO_SOT_THT:TO-220-3_Horizontal_TabDown | 2 |  | https://www.tokopedia.com/indo-ware/irf840-irf-840-irf840-irf-840
R1,R6 | 1kΩ | -- mixed values -- | 3 |  | https://www.tokopedia.com/elantech/resistor-yageo-1k-1-4w-1-0-25w-1-k-1-4-w-1-kilo-ohm-elantech
R2 | 5.6kΩ | Resistor_THT:R_Axial_DIN0204_L3.6mm_D1.6mm_P7.62mm_Horizontal | 2 |  | https://www.tokopedia.com/elantech/resistor-yageo-5k6-1-4w-1-0-25w-5-6k-1-4-w-5-6-kilo-ohm-elantech
R3 | 330Ω | Resistor_THT:R_Axial_DIN0204_L3.6mm_D1.6mm_P7.62mm_Horizontal | 3 |  | https://www.tokopedia.com/elantech/resistor-yageo-330r-1-4w-1-0-25w-1-4-w-330-ohm-elantech
R4 | R | Resistor_THT:R_Axial_DIN0204_L3.6mm_D1.6mm_P7.62mm_Horizontal | 1
R5 | 4.7kΩ | Resistor_THT:R_Axial_DIN0204_L3.6mm_D1.6mm_P7.62mm_Horizontal | 1 |  | https://www.tokopedia.com/elantech/resistor-yageo-4k7-1-4w-1-0-25w-4-7k-1-4-w-4-7-kilo-ohm-elantech
R7 | 10kΩ | Resistor_THT:R_Axial_DIN0204_L3.6mm_D1.6mm_P7.62mm_Horizontal | 1 |  | https://www.tokopedia.com/elantech/resistor-yageo-10k-1-4w-1-0-25w-1-4-w-10-kilo-ohm-elantech
R8,R9 | 3.3Ω | Resistor_THT:R_Axial_DIN0414_L11.9mm_D4.5mm_P20.32mm_Horizontal | 2 |  | https://www.tokopedia.com/elantech/resistor-3r3-2w-uniohm-metal-oxide-3-3-ohm-miniature-size-1w-elantech
RV1,RV2 | 1kΩ | Potentiometer_THT:Potentiometer_Bourns_3296X_Horizontal | 2 |  | https://www.tokopedia.com/indo-ware/3296x-102-1k-ohm-1-k-multiturn-trimpot-trimmer-variable-resistor
U1 | NE555P | Package_DIP:DIP-8_W7.62mm_Socket | 2 |  | https://www.tokopedia.com/indo-ware/ne555p-ne555-ne-555-ne555-ne-555-ne555p-dip-ic-precision-timer
U2 | NE5534 | Package_DIP:DIP-8_W7.62mm_Socket | 1 |  | https://www.tokopedia.com/elantech/tl071-tl-071-cp-texas-instrument-ti-ori-original-asli-elantech
 | PC817 | Package_DIP:DIP-4_W7.62mm | 2 |  | https://www.tokopedia.com/indo-ware/pc-817-pc817-817-optocoupler-photocoupler-phototransistor
 |  |  |  |  | https://www.tokopedia.com/indo-ware/soket-ic-8p-socket-ic-8-pin-8pin-dip

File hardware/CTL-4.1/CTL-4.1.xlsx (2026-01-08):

null | Sourced | Placed | References | Value | Footprint | MPN | Quantity
1 |  |  | R1, R2, R3, R4, R5, R6, R7, R8, R9, R10, R11, R15, R16, R17, R18, R19, R20 | 10k | R_1206_3216Metric_Pad1.30x1.75mm_HandSolder |  | 17
2 |  |  | R12, R13 | 5.1k | R_1206_3216Metric_Pad1.30x1.75mm_HandSolder |  | 2
3 |  |  | R14 | 0 | R_1206_3216Metric_Pad1.30x1.75mm_HandSolder |  | 1
4 |  |  | C1, C3, C5 | 100µF 50V | CP_Elec_10x10 |  | 3
5 |  |  | C2, C4, C6 | 680µF 35V | CP_Elec_10x10 |  | 3
6 |  |  | C7, C8, C11 | 100nF | C_1206_3216Metric_Pad1.33x1.80mm_HandSolder |  | 3
7 |  |  | C9 | 1µF | C_1206_3216Metric_Pad1.33x1.80mm_HandSolder |  | 1
8 |  |  | C10 | 22µF 10V | CP_EIA-3528-12_Kemet-T_Pad1.50x2.35mm_HandSolder |  | 1
9 |  |  | L1, L2, L3 | 100µH | L_12x12mm_H8mm |  | 3
10 |  |  | D1, D2, D3 | SS36 | D_SMA |  | 3
11 |  |  | D4, D5, D6 | LED | LED_1206_3216Metric_Pad1.42x1.75mm_HandSolder |  | 3
12 |  |  | D7 | BAT60A | D_SMB_Handsoldering |  | 1
13 |  |  | Q1, Q2, Q3, Q4, Q5, Q6 | BCX56 | SOT-89-3 |  | 6
14 |  |  | U6, U7 | PC817 | DIP-4_W7.62mm_Socket |  | 2
15 |  |  | U1 | LM2576S-3.3 | TO-263-5_TabPin3 |  | 1
16 |  |  | U2 | LM2576S-5 | TO-263-5_TabPin3 |  | 1
17 |  |  | U3 | LM2576S-12 | TO-263-5_TabPin3 |  | 1
18 |  |  | U4 | ~ | ESP32-S3-WROOM-1U |  | 1
19 |  |  | U5 | 4071 | DIP-14_W8.89mm_SMDSocket_LongPads |  | 1
20 |  |  | SW1, SW2 | SW_Omron_B3FS | SW_SPST_Omron_B3FS-100xP |  | 2
22 |  |  | K1 | G5V-1 | Relay_SPDT_Omron_G5V-1 |  | 1
23 |  |  | J1 | Conn_02x16_Top_Bottom | PinHeader_2x16_P2.54mm_Horizontal_NoPins |  | 1
24 |  |  | J2 | ~ | TE_1-84952-0_1x10-1MP_P1.0mm_Horizontal |  | 1
25 |  |  | J3, J4 | Conn_01x03 | JST_XH_B3B-XH-A_1x03_P2.50mm_Vertical |  | 1
27 |  |  | J5 | Conn_02x06_Odd_Even | PinHeader_2x06_P2.54mm_Vertical |  | 1
28 |  |  | J6 | Conn_01x04 | PinHeader_1x06_P2.54mm_Vertical |  | 1
29 |  |  | J7 | Conn_01x04 | PinHeader_1x04_P2.54mm_Vertical |  | 1

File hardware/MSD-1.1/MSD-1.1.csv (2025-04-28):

Id | Designator | Footprint | Quantity | Designation | Supplier and ref
1 | D3,D2 | D_DO-34_SOD68_P7.62mm_Horizontal | 2 | HER208
2 | TP2,TP3,TP1,TP4,TP7 | TestPoint_Bridge_Pitch2.54mm_Drill1.0mm | 5 | TestPoint
3 | J2 | PinHeader_1x03_P5.08mm_Horizontal_2 | 1 | Conn_01x03
4 | U3,U2 | DIP-4_W7.62mm_Socket | 2 | PC817
5 | R4,R3 | R_Axial_DIN0204_L3.6mm_D1.6mm_P7.62mm_Horizontal | 2 | 330Ω
6 | C2 | C_Rect_L7.0mm_W3.5mm_P5.00mm | 1 | 10nF 63
7 | TP6,TP5 | TestPoint_THTPad_2.0x2.0mm_Drill1.0mm_NoSilkscreen | 2 | TestPoint
8 | D1 | D_DO-35_SOD27_P7.62mm_Horizontal | 1 | byv26
9 | R1 | R_Axial_DIN0204_L3.6mm_D1.6mm_P7.62mm_Horizontal | 1 | 1kΩ
10 | L1 | L_CommonMode_Toroid_Horizontal_OD23mm_ID14mm_H8mm | 1 | L_Ferrite_Coupled
11 | C3 | C_Rect_L13.0mm_W5.0mm_P10.00mm_FKS3_FKP3_MKS4 | 1 | 0.022uF 400
12 | U1 | DIP-8_W7.62mm_Socket | 1 | NE555P
13 | C5 | C_Rect_L13.0mm_W5.0mm_P10.00mm_FKS3_FKP3_MKS4 | 1 | 100nF 400
14 | C4 | C_Rect_L7.0mm_W3.5mm_P5.00mm | 1 | 100nF 100
15 | Q1 | TO-220-3_Horizontal_TabDown | 1 | IRF840
16 | C1 | C_Rect_L7.0mm_W3.5mm_P5.00mm | 1 | 2.2nF 100
17 | C6 | CP_Radial_D12.5mm_P5.00mm | 1 | 470µF 35V
18 | R2 | R_Axial_DIN0204_L3.6mm_D1.6mm_P7.62mm_Horizontal | 1 | 5.6kΩ
19 | J1 | PinHeader_1x04_P2.54mm_Horizontal_2 | 1 | Conn_01x05

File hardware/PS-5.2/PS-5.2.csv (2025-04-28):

Id | Designator | Footprint | Quantity | Designation | Supplier and ref
1 | L1,L5,L4,L3,L6,L7,L2 | L_Axial_L9.5mm_D4.0mm_P15.24mm_Horizontal_Fastron_SMCC | 7 | L
2 | Q3,Q1,Q2 | TO-247-3_Vertical | 3 | IRFPE50
3 | D7 | D_DO-201AE_P15.24mm_Horizontal | 1 | 10A10
4 | J9,J8 | Molex_KK-396_5273-03A_1x03_P3.96mm_Vertical_2 | 2 | Conn_01x03
5 | D9,D8 | D_DO-35_SOD27_P7.62mm_Horizontal | 2 | 1N4148
6 | D2,D1,D3 | D_DO-41_SOD81_P10.16mm_Horizontal | 3 | 1N47xxA
7 | R1,R2,R3 | R_Axial_DIN0411_L9.9mm_D3.6mm_P15.24mm_Horizontal | 3 | 6.2Ω
8 | D5,D6 | D_DO-201AE_P15.24mm_Horizontal | 2 | 1.5KExxA
9 | R4 | R_Axial_DIN0204_L3.6mm_D1.6mm_P7.62mm_Horizontal | 1 | 6.2Ω
10 | C6 | C_Rect_L13.0mm_W5.0mm_P10.00mm_FKS3_FKP3_MKS4 | 1 | 2.2nF
11 | U2 | ESU-REM-4.0 | 1 | ~
12 | CR2,CR1 | TO-220-3_Vertical | 2 | ~
13 | U4 | DIP-4_W7.62mm_Socket | 1 | PC817
14 | C1,C3,C4 | C_Rect_L7.2mm_W3.5mm_P5.00mm_FKS2_FKP2_MKS2_MKP2 | 3 | 100nF
15 | U1 | DIP-8_W7.62mm | 1 | TC4422
16 | J3,J2 | Molex_KK-396_5273-05A_1x05_P3.96mm_Vertical_2 | 2 | Conn_01x05
17 | C2 | CP_Radial_D22.0mm_P10.00mm_SnapIn | 1 | C_Polarized
18 | U3 | ESU-MSD-1.0 | 1 | ~
19 | J1 | PinSocket_1x16_P2.54mm_Vertical_2 | 1 | Conn_01x16
20 | CON-01 | KF7.62-4Pole | 1 | Screw_Terminal_01x04
21 | K1,K2 | Relay_SPDT_RAYEX-L90 | 2 | RAYEX-L90
22 | C5 | C_Rect_L13.0mm_W5.0mm_P10.00mm_FKS3_FKP3_MKS4 | 1 | 6.8nF
23 | D4 | D_DO-201AE_P15.24mm_Horizontal | 1 | SB5H100
24 | R5 | R_Axial_DIN0516_L15.5mm_D5.0mm_P20.32mm_Horizontal | 1 | 120Ω

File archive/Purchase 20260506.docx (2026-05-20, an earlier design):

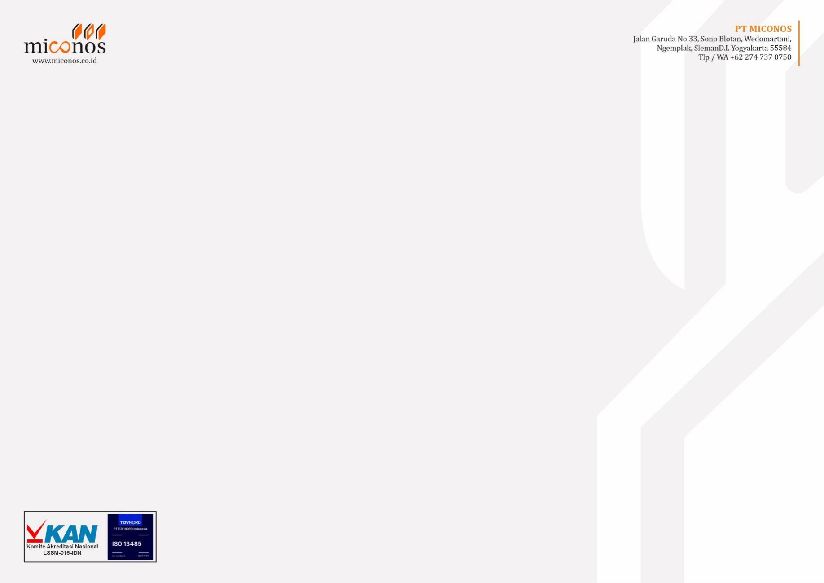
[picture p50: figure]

PURCHASE REQUEST
No. 0201/PR/MTN/2026

Nama Pemohon : Marga Budi Tanggal pengajuan : 06 Mei 2026

Ditujukan Kepada : Purchasing Tanggal pemesanan :

No | Nama Barang | Deskripsi | Jumlah | Harga (Rp) | Alasan Pembelian
1. | power meter D52-2066 | Alat ukur daya | 1 | 122.400 | Pengukuran daya dan sinyal ESU
2. | oscilloscope probe P4100 | oscilloscope probe 100x | 1 | 214.000
3.

Pemohon | Diverifikasi Oleh | Disetujui Oleh

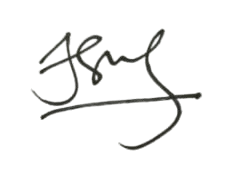
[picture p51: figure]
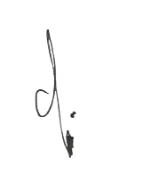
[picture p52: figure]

| Finance | Purchasing

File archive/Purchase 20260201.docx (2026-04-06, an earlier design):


PURCHASE REQUEST
No. 0201/PR/MTN/2026

Nama Pemohon : Marga Tanggal pengajuan : 09 Februari 2026

Ditujukan Kepada : Purchasing Tanggal pemesanan : 09 Februari 2026

No | Nama Barang | Deskripsi | Jumlah | Harga (Rp) | Alasan Pembelian
1. | Komponen kontroler ESU | BoM untuk PCB kontroler ESU | 1 Set | 627,605 | Riset No Stock
2.
3.

Pemohon | Diverifikasi Oleh | Disetujui Oleh

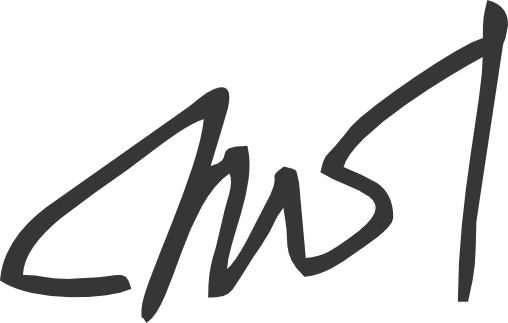
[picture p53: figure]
Signature - Marga

| Finance | Purchasing

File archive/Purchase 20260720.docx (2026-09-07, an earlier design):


PURCHASE REQUEST
No. 0201/PR/MTN/2026

Nama Pemohon : Marga Budi Tanggal pengajuan : 20 Juli 2026

Ditujukan Kepada : Purchasing Tanggal pemesanan :

No | Nama Barang | Deskripsi | Jumlah | Harga (Rp) | Alasan Pembelian
1. | Resistor flange 50Ω 100W | Beban semu ESU | 10 | 57.650 | Pengukuran daya dan sinyal ESU
2.
3.

Pemohon | Diverifikasi Oleh | Disetujui Oleh


| Finance | Purchasing

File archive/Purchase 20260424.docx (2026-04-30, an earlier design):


PURCHASE REQUEST
No. 0201/PR/MTN/2026

Nama Pemohon : Marga Budi Tanggal pengajuan : 24 April 2026

Ditujukan Kepada : Purchasing Tanggal pemesanan :

No | Nama Barang | Deskripsi | Jumlah | Harga (Rp) | Alasan Pembelian
1. | Sensor neutral pad ESU | Komponen pengondisi sinyal REM pada neutral pad ESU | 1 | 163.100 | Riset
2.
3.

Pemohon | Diverifikasi Oleh | Disetujui Oleh


| Finance | Purchasing

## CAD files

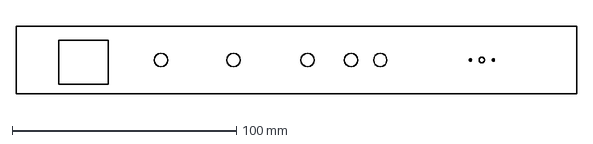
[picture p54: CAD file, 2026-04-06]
CAD/FR_TEST.dxf
250.0 x 30.0 mm

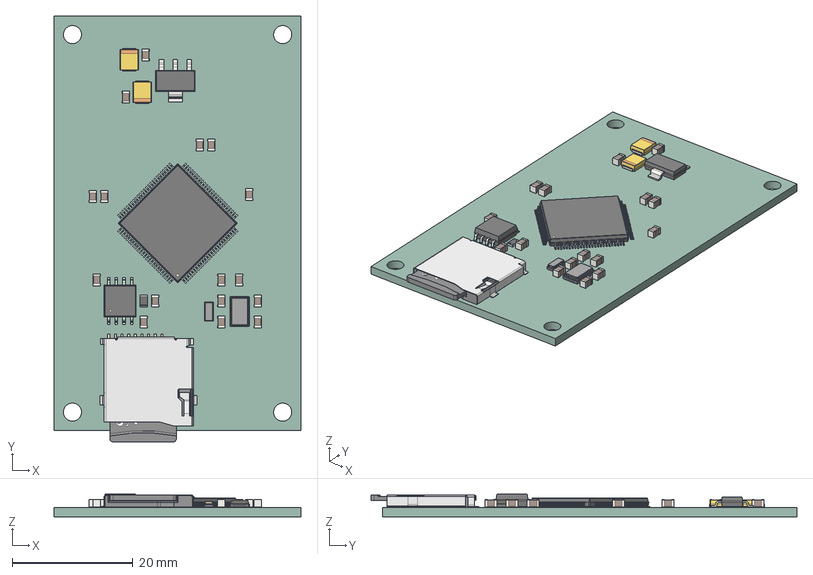
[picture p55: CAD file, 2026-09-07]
hardware/CTL-7.0/.step
40.9 x 70.5 x 3.75 mm
C_0805_2012Metric x 16
Crystal_SMD_3215-2Pin_3.2x1.5mm
CP_EIA_3528_12_Kemet_T x 2
Crystal_SMD_5032-2Pin_5.0x3.2mm
R_0805_2012Metric
SOT-223
LQFP-100_14x14mm_P0.5mm
SOIC-8_5.3x5.3mm_P1.27mm
Frame
MicroSD
Pin1
Pin2
Pin3
Pin4
Pin5
Pin6
Pin7
Pin8
Pin9
CTL-7.0_PCB

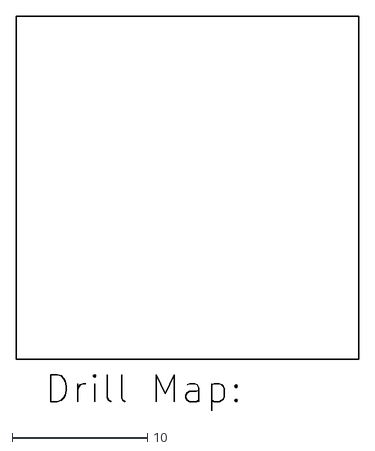
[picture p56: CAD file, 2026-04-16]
hardware/INA-2.0/fabrication-outputs/INA-2.0-NPTH-drl_map.dxf
25.4 x 29.2

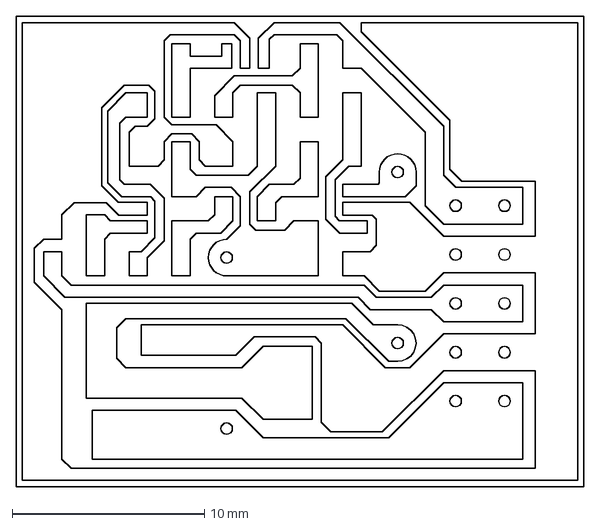
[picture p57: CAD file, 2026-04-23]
hardware/INA-3.1/fabrication-outputs/INA-3-TRACE.dxf
29.5 x 24.4 mm

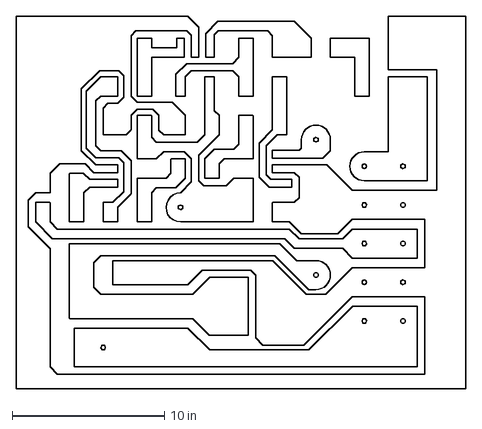
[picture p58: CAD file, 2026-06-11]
hardware/INA-3/fabrication-outputs/TRACE.dxf
29.5 x 24.5 in

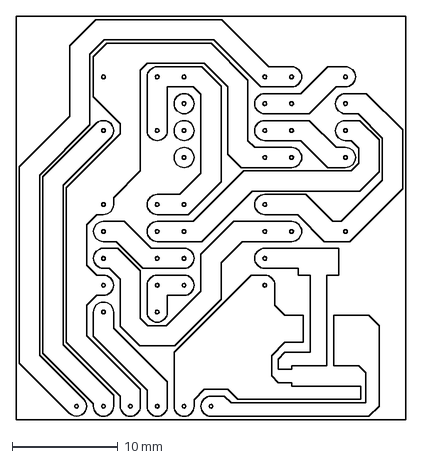
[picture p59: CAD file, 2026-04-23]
hardware/INA-4.0/fabrication-outputs/TRACE-4.dxf
36.8 x 38.1 mm

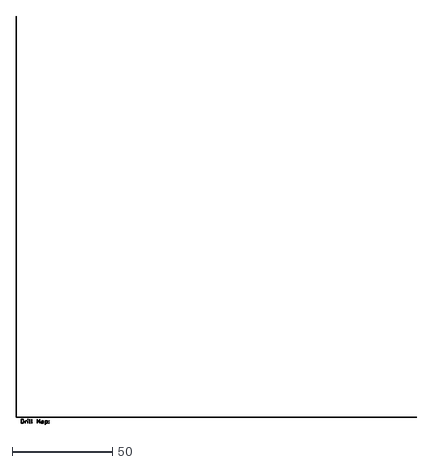
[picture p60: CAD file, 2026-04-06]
hardware/PS-5.1/fabrication-output/PS-5.1-NPTH-drl_map.dxf
199.4 x 203.2

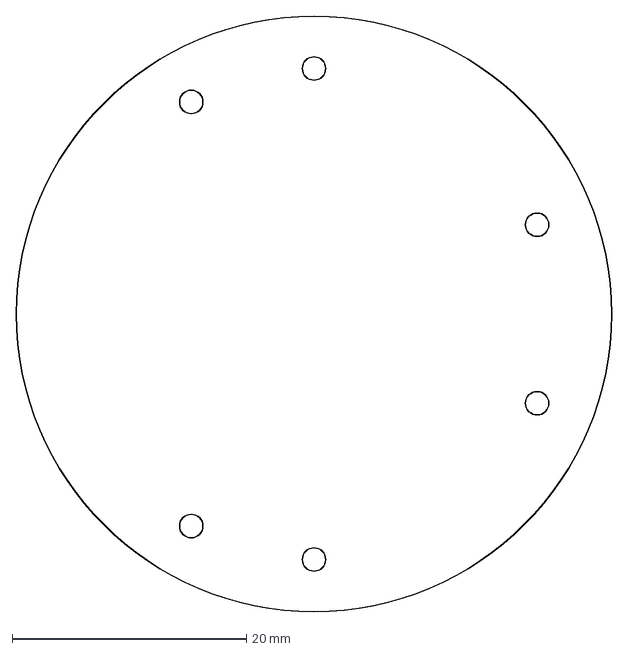
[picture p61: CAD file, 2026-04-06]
hardware/PS-5.1/XF-FOOTPRINT.dxf
50.8 x 50.8 mm

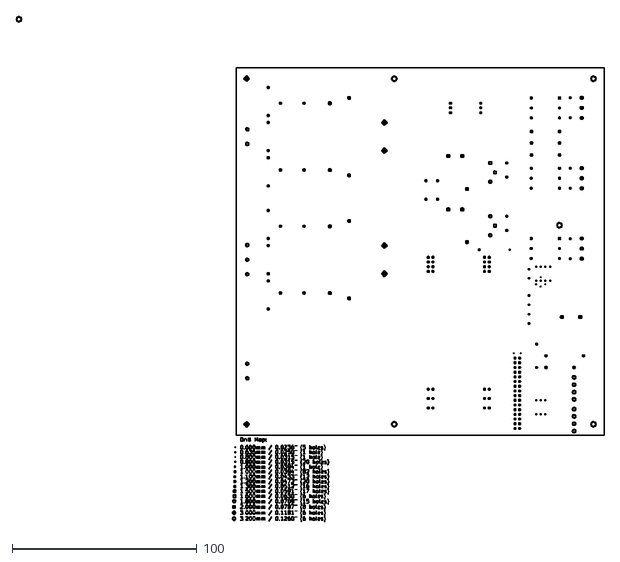
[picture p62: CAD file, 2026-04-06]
hardware/PS-5.2/fabrication-output/PS-5.1-PTH-drl_map.dxf
318.6 x 273.9

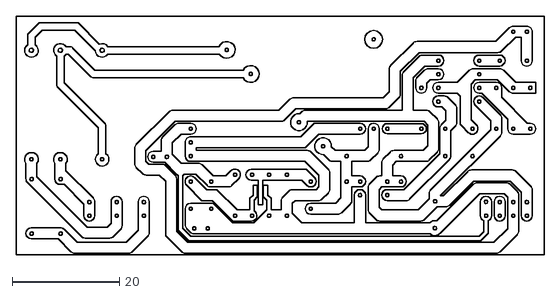
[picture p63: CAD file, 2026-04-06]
hardware/REM-4.0/fabrication-output/TRACE.dxf
98.5 x 44.5

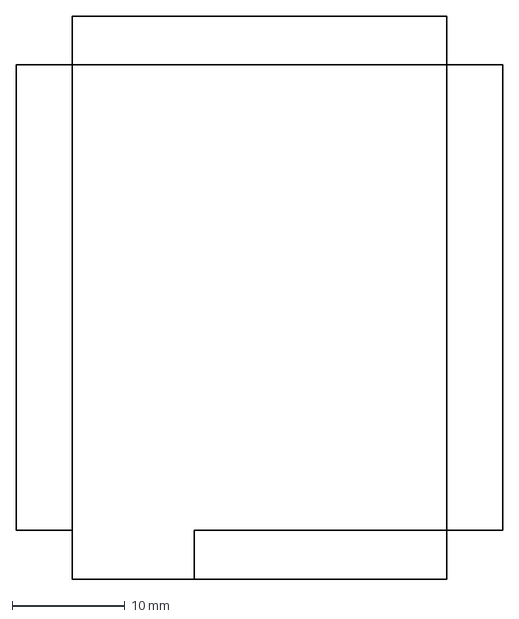
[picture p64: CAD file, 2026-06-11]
hardware/REM-5.0/SHIELD_2.dxf
43.2 x 49.9 mm

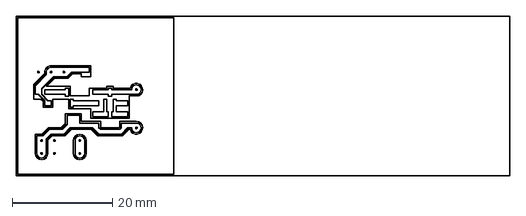
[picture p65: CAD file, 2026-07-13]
hardware/REM-7.0/fabrication output/TRACE_TOP.dxf
98.4 x 31.8 mm

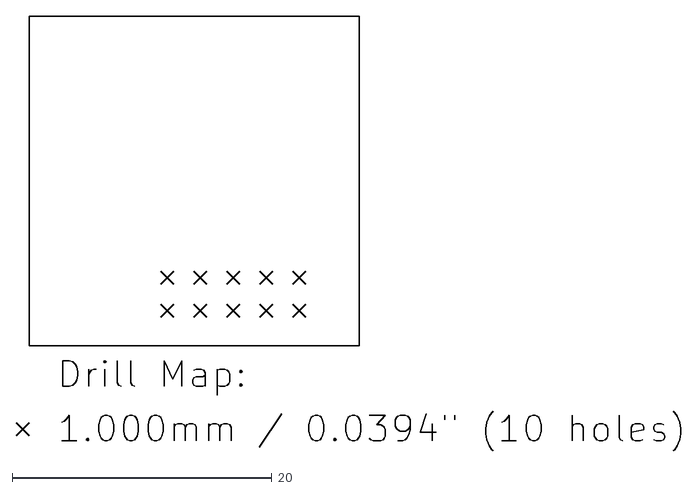
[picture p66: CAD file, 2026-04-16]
hardware/INA-2.0/fabrication-outputs/INA-2.0-PTH-drl_map.dxf
51.2 x 33.5

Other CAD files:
hardware/REM-5.0/fabrication-output/TRACE_BOT_2.dwg
sine.dwg
CAD/test-probe.dwg
hardware/CTL-7.0/CTL-7.0.step
CAD/enclosure.dwg
CAD/front-panel.dwg
CAD/socket-bipolar-v1.dwg
CAD/socket-monopolar-v1.dwg
CAD/socket-re-v1.dwg
archive/refferences/MiniSTM32H7xx-master/Hardware/STM32H7xx CoreBoard WeAct Studio V12 3D.step
archive/refferences/MiniSTM32H7xx-master/Hardware/legacy version/STM32H7xx CoreBoard WeAct Studio V10 3D.step
archive/sine.dwg
hardware/INA-2.0/fabrication-outputs/INA-1.0-F_Cu.dxf
hardware/INA-2.0/fabrication-outputs/INA-1.0-F_Mask.dxf
hardware/INA-2.0/fabrication-outputs/INA-1.0-NPTH-drl_map.dxf
hardware/INA-2.0/fabrication-outputs/INA-1.0-PTH-drl_map.dxf
hardware/INA-2.0/fabrication-outputs/INA-2.0-F_Cu.dxf
hardware/INA-2.0/fabrication-outputs/INA-2.0-F_Mask.dxf
hardware/INA-2.0/fabrication-outputs/TRACE-2.dwg
hardware/INA-2.0/fabrication-outputs/TRACE-2.dxf
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

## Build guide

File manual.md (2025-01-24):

# ESU
Generate RF current

Mode:
- Monopolar
  - Cut
    - Pure (Unmodulated Sine Wave)
    - Blend 1 (Modulated Sine Wave 1)
      Faster cutting speed
      Small amount bleeding treatment
    - Blend 2 (Modulated Sine Wave 2)
      Slower cutting speed
      Extensive amount bleeding treatment
  - Coagulation
    - Spray
      - Provides surface coagulation with shallow penetration.
      - Facilitates tissue removal.
      - Operates with high output peak voltage.
    - Forced
      - Achieves blood coagulation in a small area.
      - Operates with low output peak voltage.
- Bipolar

Automatically monitor:
- the existence of Return Electrode
- the connection between Generator and Contact area

## Performance Features
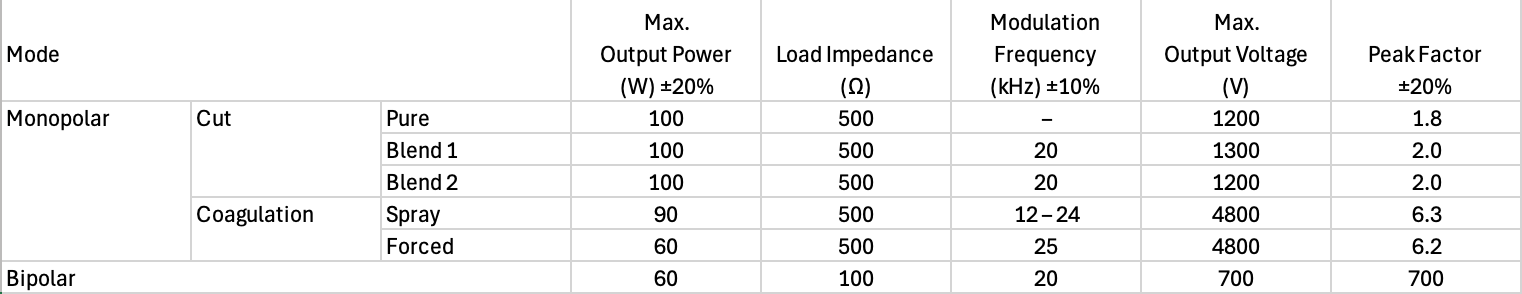
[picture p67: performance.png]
performance

- Input voltage is AC220V 50Hz
- Input power 1000VA
- Fuse F6AL250V
- The frequency of each mode is 416kHz ±10%
- The resistance of the contact area must be lower than 150Ω; otherwise, the generator will emit sound and light alert signals.

## Security
### Type I (Class I) electric shock protection
Type I protection represents a fundamental electrical safety classification that provides basic level protection for electrical equipment. It is designed to protect users from macro-shock through a combination of basic insulation and protective earthing, making it suitable for general electrical equipment applications.
- Basic Insulation
  - Primary protective layer
  - Insulates all live electrical parts
  - Prevents direct contact with current-carrying components
- Protective Earth Connection
  - Secondary safety measure
  - Connects exposed conductive parts to ground

Identification
- Marked with earth symbol (⏚)
- Uses yellow/green earth wire
- Standard power connectors

_Complies with IEC 60601-1 for medical devices_

Under normal operating conditions, the basic insulation serves as a barrier that prevents any contact with live electrical parts, ensuring the equipment operates safely. However, if this basic insulation fails, the protective system responds immediately: the fault current is directed through the protective earth connection, which triggers the circuit breaker or fuse to activate, cutting off the power supply before the user can be exposed to dangerous electrical shock.

### CF Applied Part
CF Applied Part represents the highest level of medical device protection, specifically engineered for direct cardiac applications. It is meticulously designed to protect patients from potentially lethal micro-shock during cardiac procedures, making it essential for any equipment that comes into direct contact with the heart.
- Multiple Isolation Barriers
  - Primary isolation through reinforced insulation
  - Secondary isolation via transformer coupling
  - Additional protective layers for enhanced safety
  - Specialized shielding against interference
- Floating Design
  - Electrically isolated from ground and other circuits
  - Independent power supply system
  - Galvanic separation from main power
  - Protected against defibrillator discharge effects
This floating design enables:
- Extremely low leakage current (10µA normal, 50µA fault)
  - Critical for preventing micro-shock to the heart
  - Only possible because of the complete isolation
- Very high isolation voltage (>4000V)
  - Achieved through multiple isolation barriers
  - Necessary to withstand defibrillation pulses
- Defibrillation-proof capability
  - Protected against high-voltage defibrillator discharge
  - Essential for cardiac emergency situations

Under normal operating conditions, the multiple isolation barriers and floating design work together to completely isolate the patient circuit from any electrical sources. The floating design maintains extremely low leakage current (10µA) and high isolation voltage (>4000V), ensuring safe direct cardiac contact. If any fault occurs, the system's independent isolation layers provide redundant protection: even if one barrier fails, the remaining isolation systems maintain patient safety by keeping leakage current below 50µA. Additionally, if a defibrillator discharge occurs during cardiac emergency, the high isolation voltage and floating design protect both the patient and the equipment by absorbing and dispersing the high-voltage pulse without compromising the isolation system.

Think of it like a chain of protection:
```
Floating Design
  → Complete Isolation
    → Low Leakage Current
    → High Isolation Voltage
    → Defibrillation Protection
```

Identification
- Marked with CF symbol (♡)
- Often uses orange color coding
- Specific medical connectors

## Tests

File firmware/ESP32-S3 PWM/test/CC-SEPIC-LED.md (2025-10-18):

constant‑current SEPIC (buck‑boost) LED driver with pure analog dimming (no PWM).

### Topology
- SEPIC with LM3478 so it regulates LED current when Vin crosses VLED (3.2–4.2 V battery, ~3.0–3.3 V LED).
- Constant current via low‑side sense resistor and a small op‑amp that translates sense voltage to the LM3478 `FB` reference (1.26 V).
- Analog dimming by varying the op‑amp reference from 0–1.26 V.

### Concrete example (fill in your LED current if different)
- Assumptions: White LED Vf ≈ 3.0–3.2 V at ILED = 350 mA, Vin = 3.2–4.2 V, fSW ≈ 600 kHz.

Key parts
- Controller: LM3478
- MOSFET: 30 V logic‑level, low Qg/Rds(on) (e.g., SiS412DN, IRLML6344, AO3400A class)
- Diode: Schottky, ≥40 V, ≥1 A (e.g., B240A, SS24)
- Inductors: L1 = L2 = 4.7 µH, shielded, Isat ≥ 2 A, low DCR. Coupled inductor optional to reduce ripple.
- SEPIC cap: 10 µF, 16 V, X7R
- Output cap: 22–47 µF, 10 V, low ESR
- Input cap: 22–47 µF, 10 V, low ESR
- Switch current sense (LM3478 `ISEN`): 0.1 Ω (tune per peak current)
- LED current sense (low‑side): Rsense = 0.1 Ω, 0.5 W
- Op‑amp: Rail‑to‑rail 5 V, GBW ≥ 1 MHz (e.g., TLV9061, MCP6001U for lower BW)

Current regulation and analog dim
- LM3478 `FB` ref = 1.26 V. Sense LED current: Vsense = ILED × Rsense.
- With Rsense = 0.1 Ω at 0.35 A → 35 mV. Amplify to 1.26 V with non‑inverting gain ≈ 36.
  - Example op‑amp resistors: Rin = 3.48 kΩ, Rf = 118 kΩ (gain = 1 + 118/3.48 ≈ 34); trim to hit exactly 1.26 V at full current.
- Provide a reference to the inverting input to enable analog dim:
  - Vref_dim range 0–1.26 V sets 0–100% ILED.
  - Generate Vref_dim with a pot to a stable reference (e.g., TLV431‑based 1.25 V) or a DAC from your MCU.
  - Wire as differential amp so the op‑amp drives `FB` = 1.26 V when (A × Vsense) = Vref_dim. As you reduce Vref_dim, ILED reduces proportionally to zero.

Power‑stage sizing (starting values)
- fSW: 600 kHz (use RT from datasheet; ~18 kΩ for ~600 kHz)
- Duty (worst‑case) around 50–60% at Vin ≈ VLED; SEPIC ripple currents similar in L1/L2.
- Inductors: pick ΔIL ≈ 30–40% of average; 4.7 µH is a good start for 600 kHz here.
- SEPIC coupling cap: 10 µF X7R; keep ESR/ESL low and place tight to L1/L2/diode.
- Slope compensation: per datasheet; start with R/C from `ISEN` node as recommended example and tune if subharmonics appear.
- MOSFET/diode voltage stress: choose ≥20–30 V ratings; SEPIC diode sees roughly Vin+Vout.

COMP network
- Start with Rc ≈ 10 kΩ, Cc ≈ 3.3 nF, Cf ≈ 100 pF on `COMP` (fine‑tune for stable transient response once the current loop is active).

Wiring notes
- LED and Rsense at low side to ground for simple sensing; short, Kelvin sense to op‑amp.
- Op‑amp output drives LM3478 `FB`; do not use the normal output voltage divider.
- Keep the high‑di/dt loop (MOSFET–L1–diode–SEPIC cap) extremely tight; use a solid ground plane.
- Use shielded inductors to reduce EMI; add small RC snubbers if needed on switch node.

Dimming behavior
- Smooth, flicker‑free analog 0–100% by sweeping Vref_dim 0–1.26 V.
- For absolute zero current, let Vref_dim go to 0 V; also tie LM3478 `SHDN` to your control if you want hard‑off.

To finalize exact values, I need:
- LED nominal forward voltage at your target max current
- Desired max current (mA)
- Any size/EMI frequency preference (e.g., ≥1 MHz)
- Whether you can include a small op‑amp, or prefer a current‑sense amplifier IC (e.g., INA180/INA199) instead

I’ll then compute precise Rsense, op‑amp gain, RT, inductor/cap selections, and a tested COMP network.

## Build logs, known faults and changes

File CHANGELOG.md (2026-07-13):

# CHANGELOG
All notable changes to this **ESU** project will be documented in this file.

The format is based on [Keep a Changelog](https://keepachangelog.com/en/2.0.0/),
and this project adheres to [Semantic Versioning](https://semver.org/spec/v2.0.0.html).

## [Unreleased]
### Added
-   Hasil uji `hardware/REM-7.0`, REM Signal vs. Neutral Pad Resistance
-   `hardware/CTL-5.0`, menghapus blok Power Supply (Buck Converter 12V dan 5V) dan menambahkan blok INA-3.0
-   `hardware/PSU-1.0`, board Power Supply (Buck Converter 12V dan 5V) yang dipisahkan dari CTL-4.0
-   `hardware/PS-6.0`, penyesuaian letak edge connector karena perubahan board yang digunakan: CTL, PSU, MSD, dan REM.
-   Firmware `ESU_V1`: `feat/adaptive-REM-Lower-upper-limit`, fungsi `calculateREMLimit()` dengan metode Map-based Control untuk menentukan `REM_LOWER_LIMIT` dan `REM_UPPER_LIMIT` berdasarkan power setting pada output monopolar.
-   Firmware `ESU_V1`: `feat/adaptive-rmt-output`, fungsi `setDuration()` untuk `rmt output` dengan metode Map-based Control berdasarkan Power Setting.

### Changed
-   Perbaikan code `readREM()` pada average samples dan fixed-point IIR filtering untuk stabilitas pembacaan REM saat trigger monopolar aktif di power tinggi (EMI effect)

### Fixed
-   Masalah noise yang ditimbulkan EMI yang mempengaruhi pembacaan REM saat trigger monopolar aktif

## [1.0.3] 2026-06-25
### Stack
-   Hardware
    - `PS-5.0`
    - `CTL-4.0`
    - `MSD-1.1`
    - `REM-7.0`
-   Firmware `ESU_V1`
-   UI

### Added
-   File PCB `hardware/REM-7.0`, reverse engineering dari REM board `TAKTVOLL v1.0 230927`
    - Versi sebelumnya terkendala pada stabilitas pembacaan saat trigger monopolar aktif di power tinggi (EMI effect).
    - Versi ini menerapkan komponen SMD pada sisi primer, desain double layer dengan top-bottom ground plane serta ruang soldering untuk can-style copper plate sebagai Faraday Cage.
-   File .pdf .dxf `hardware/REM-7.0`, untuk membuat trace pada copper board menggunakan laser.

## [1.0.1] 2026-01-01
### Added
-   File PCB `hardware/INA-3.0`, modul instrument amplifier untuk mengondisikan sinyal REM agar memiliki rentang pembacaan 0 - 5V.
-   Firmware controller `firmware/ESU_V1`

## [1.0.0] 2026-01-01
### Stack
-   Hardware
    - `PS-5.0`
    - `CTL-4.0`
    - `MSD-1.1`
    - `REM-4.0`
-   Firmware `ESU_V1`
-   UI

### Added
-   PCB Design file `hardware/PS-5.0`
-   PCB Design file `hardware/CTL-4.0`
-   PCB Design file `hardware/MSD-1.1`
-   PCB Design file `hardware/REM-4.0`
-   Firmware display `ui`
-   Firmware controller `firmware/ESP32-S3 PWM`

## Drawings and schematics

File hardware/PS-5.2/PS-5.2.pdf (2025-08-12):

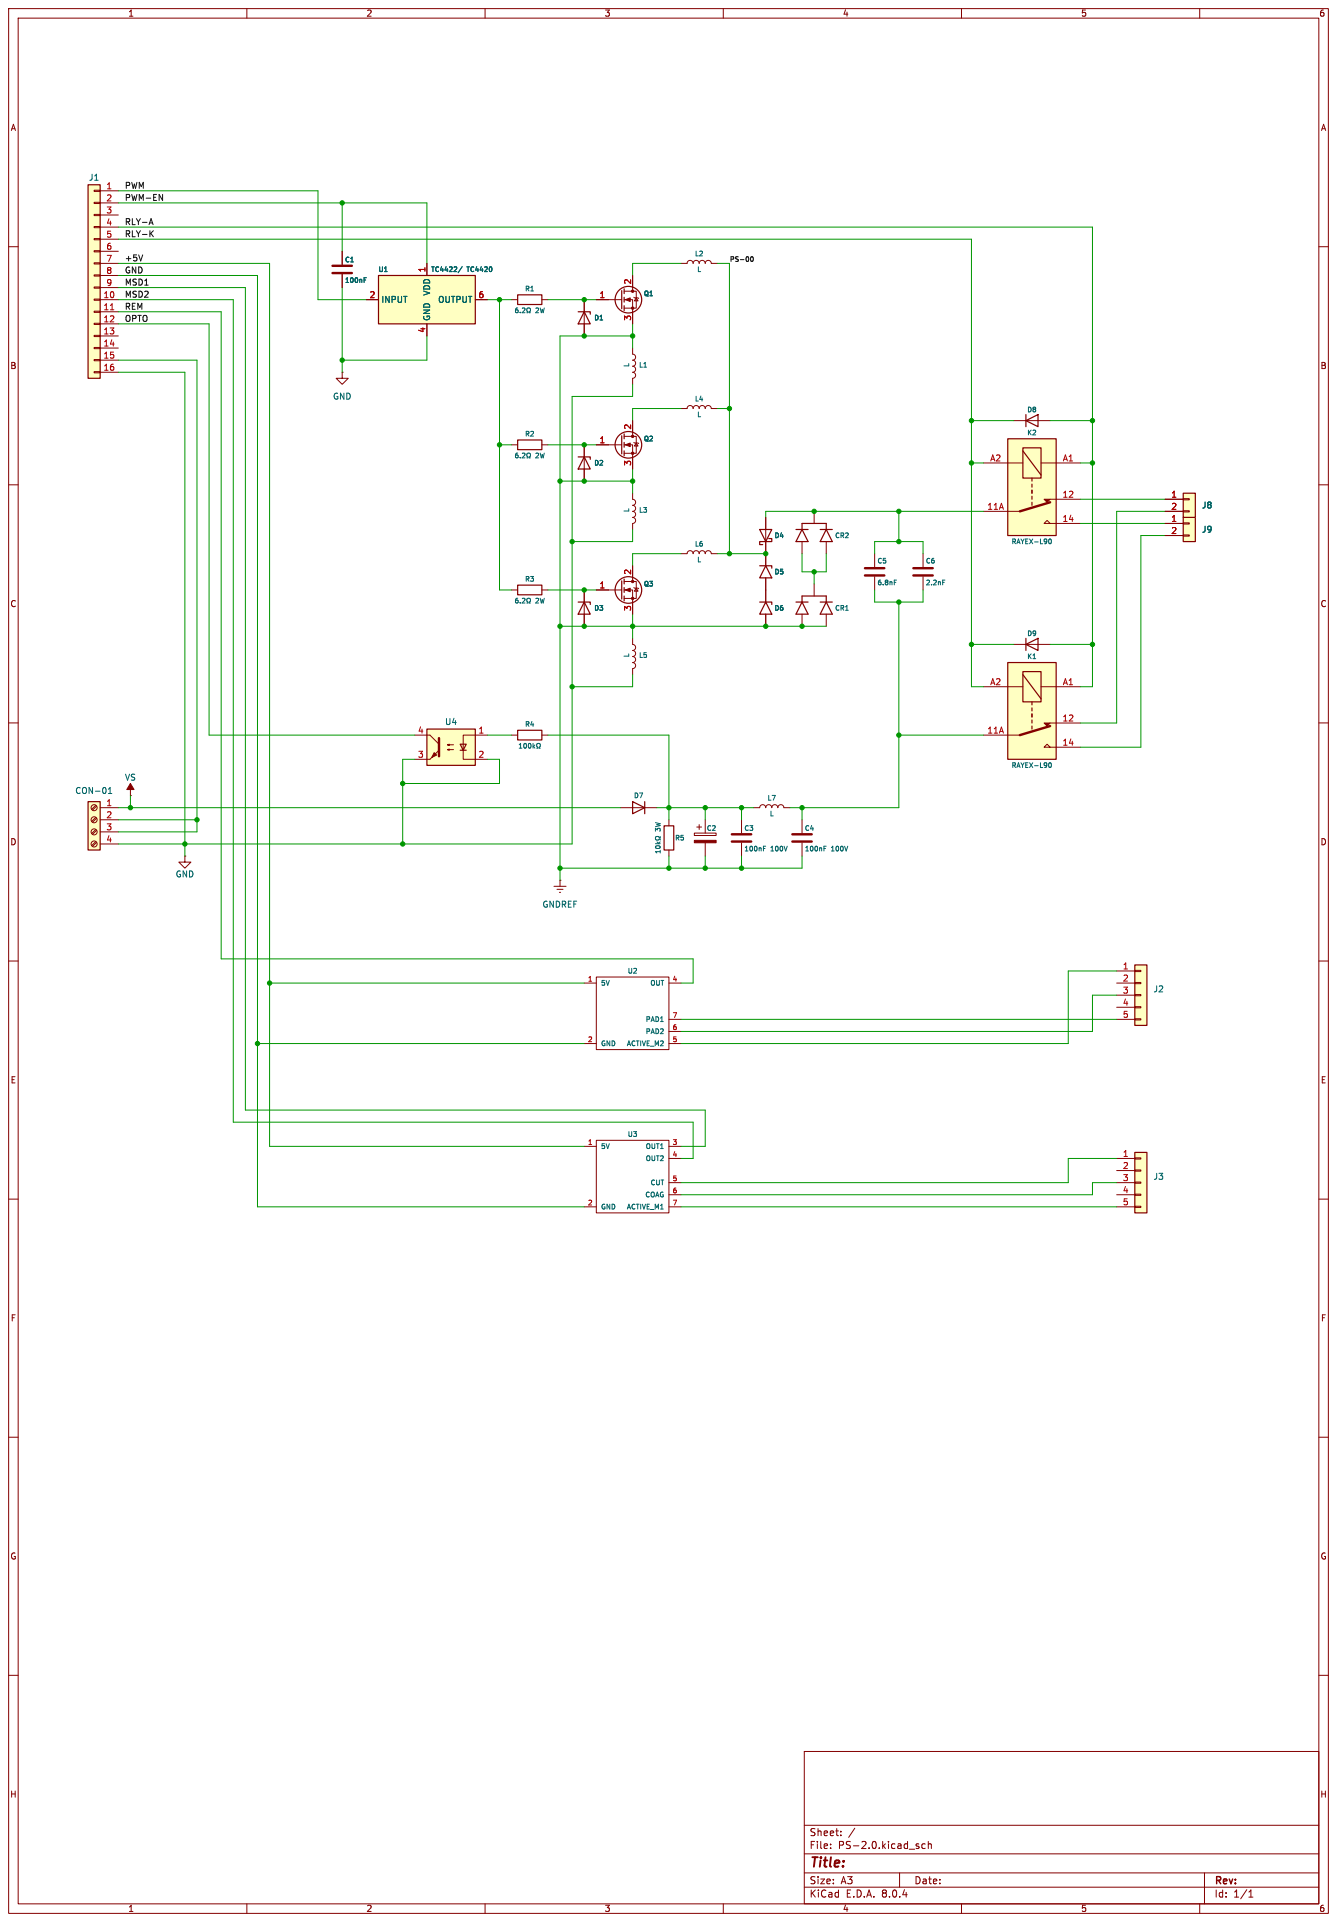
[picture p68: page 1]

PWM-EN OPTO MSD1 PWM 5

3 4 RLY-A

+5V RLY-K 6 7

Id: 1/1 Title: File: PS-2.0.kicad_sch Sheet: /

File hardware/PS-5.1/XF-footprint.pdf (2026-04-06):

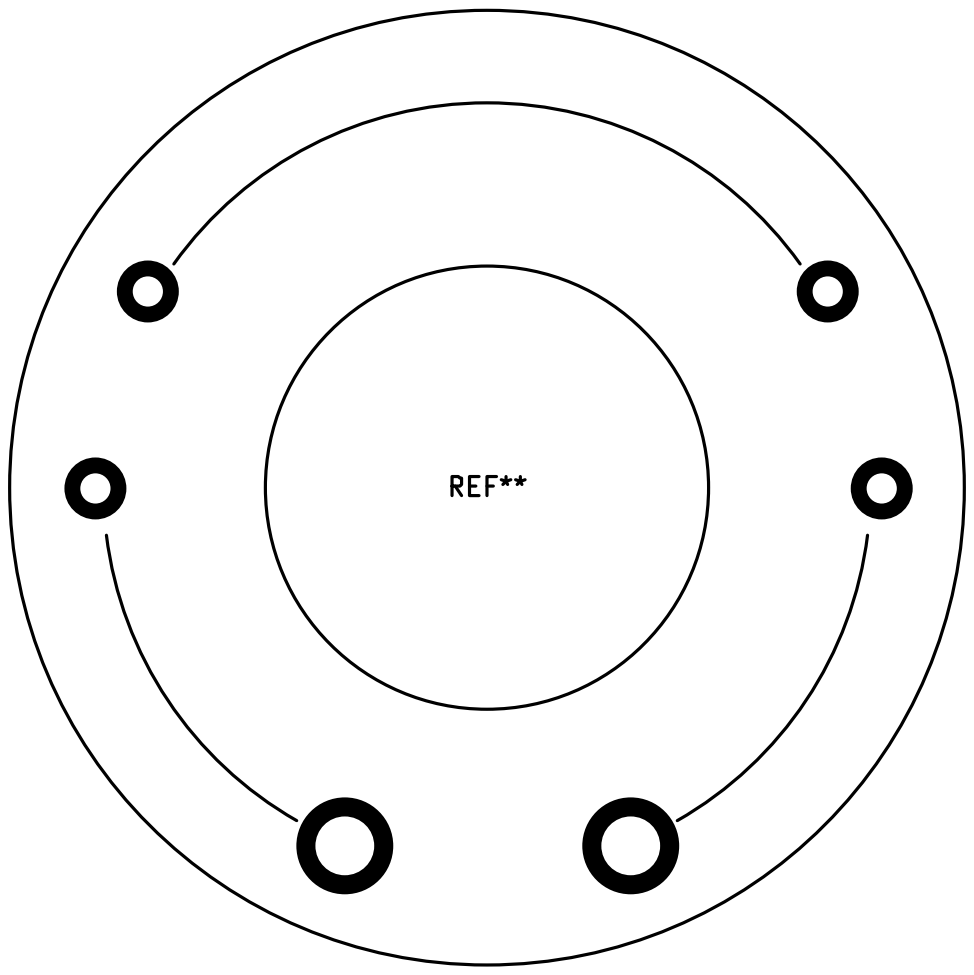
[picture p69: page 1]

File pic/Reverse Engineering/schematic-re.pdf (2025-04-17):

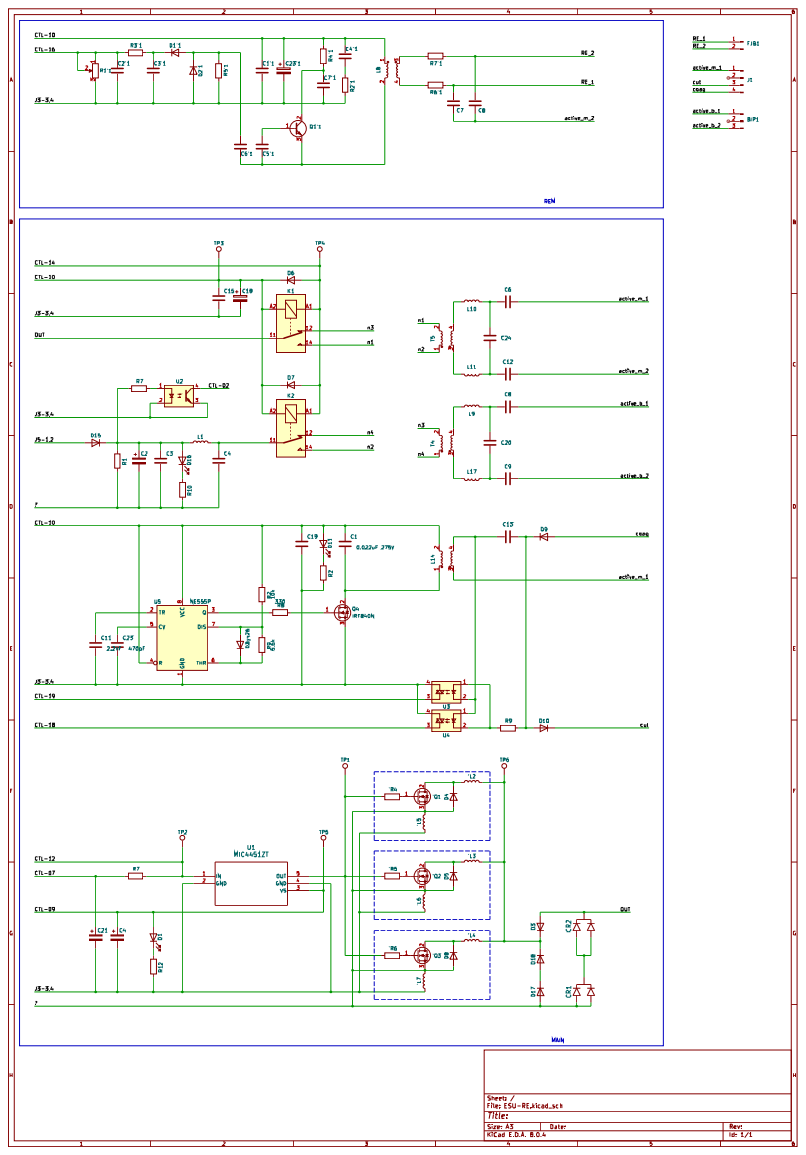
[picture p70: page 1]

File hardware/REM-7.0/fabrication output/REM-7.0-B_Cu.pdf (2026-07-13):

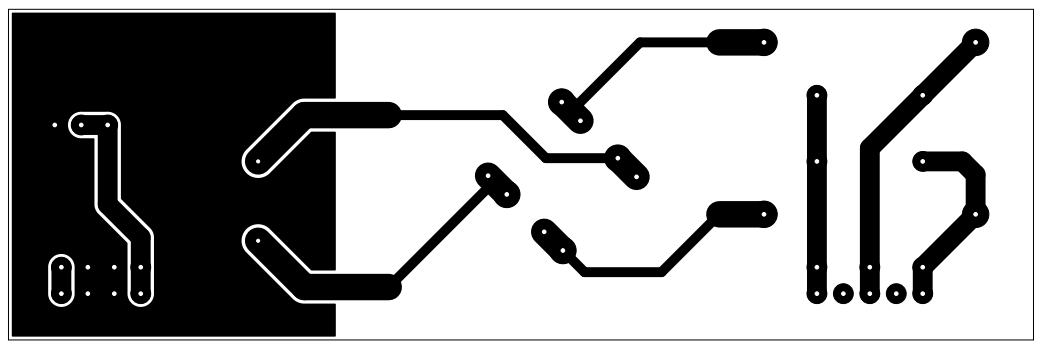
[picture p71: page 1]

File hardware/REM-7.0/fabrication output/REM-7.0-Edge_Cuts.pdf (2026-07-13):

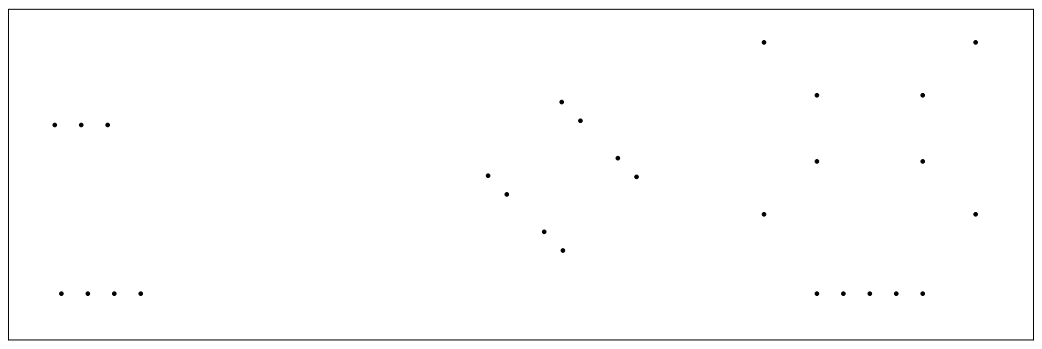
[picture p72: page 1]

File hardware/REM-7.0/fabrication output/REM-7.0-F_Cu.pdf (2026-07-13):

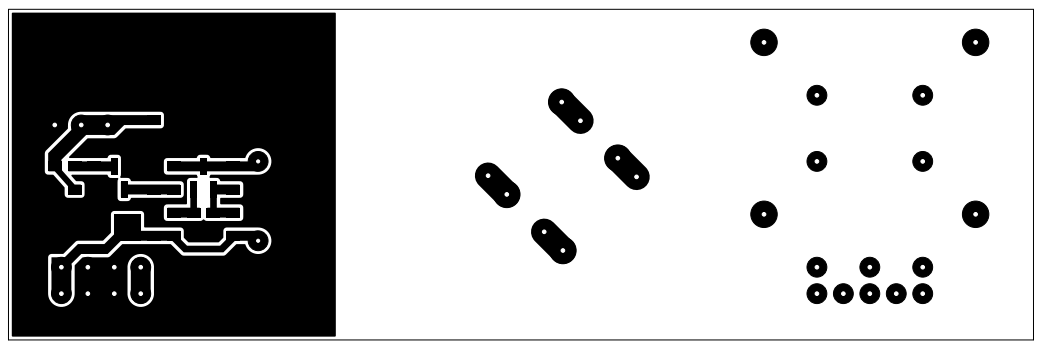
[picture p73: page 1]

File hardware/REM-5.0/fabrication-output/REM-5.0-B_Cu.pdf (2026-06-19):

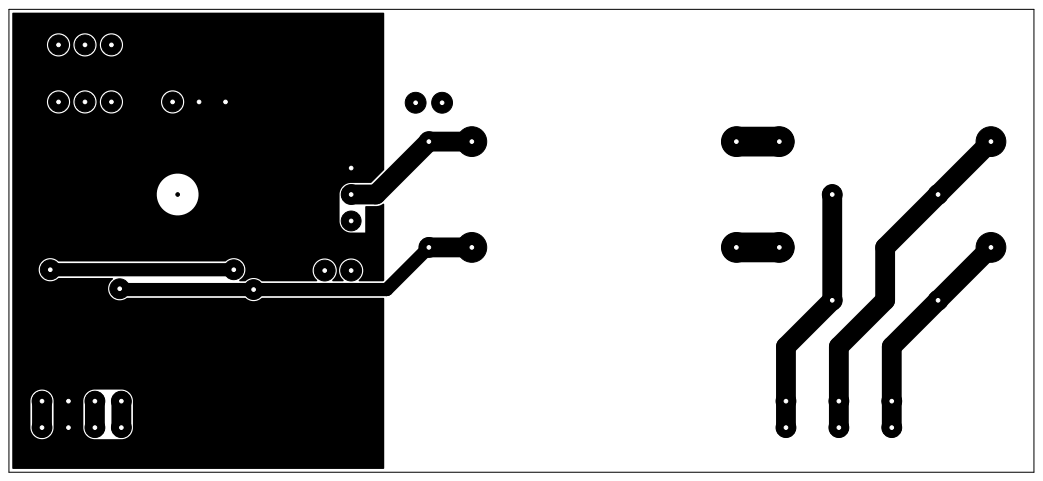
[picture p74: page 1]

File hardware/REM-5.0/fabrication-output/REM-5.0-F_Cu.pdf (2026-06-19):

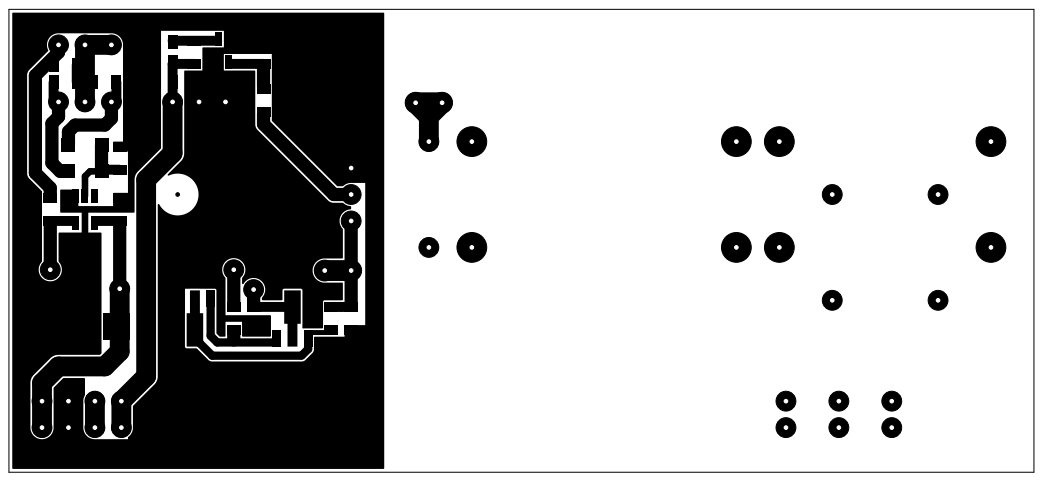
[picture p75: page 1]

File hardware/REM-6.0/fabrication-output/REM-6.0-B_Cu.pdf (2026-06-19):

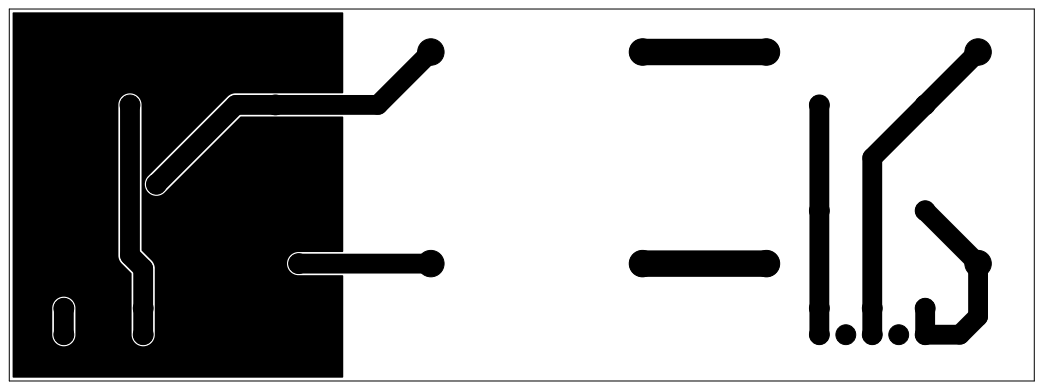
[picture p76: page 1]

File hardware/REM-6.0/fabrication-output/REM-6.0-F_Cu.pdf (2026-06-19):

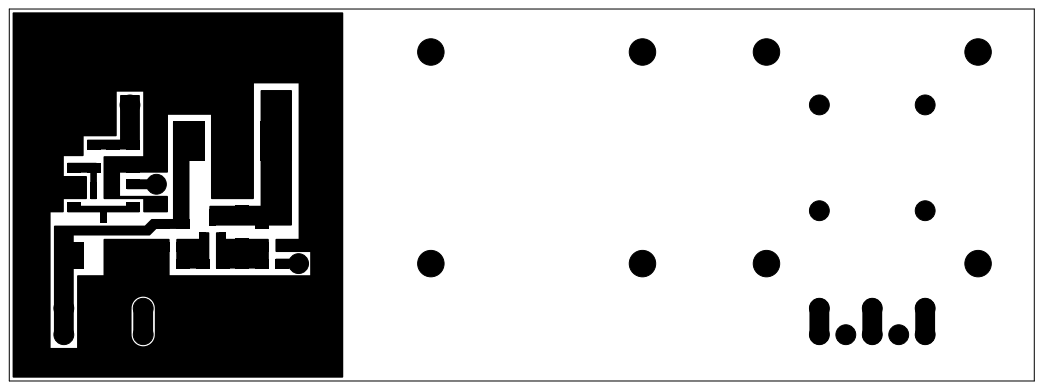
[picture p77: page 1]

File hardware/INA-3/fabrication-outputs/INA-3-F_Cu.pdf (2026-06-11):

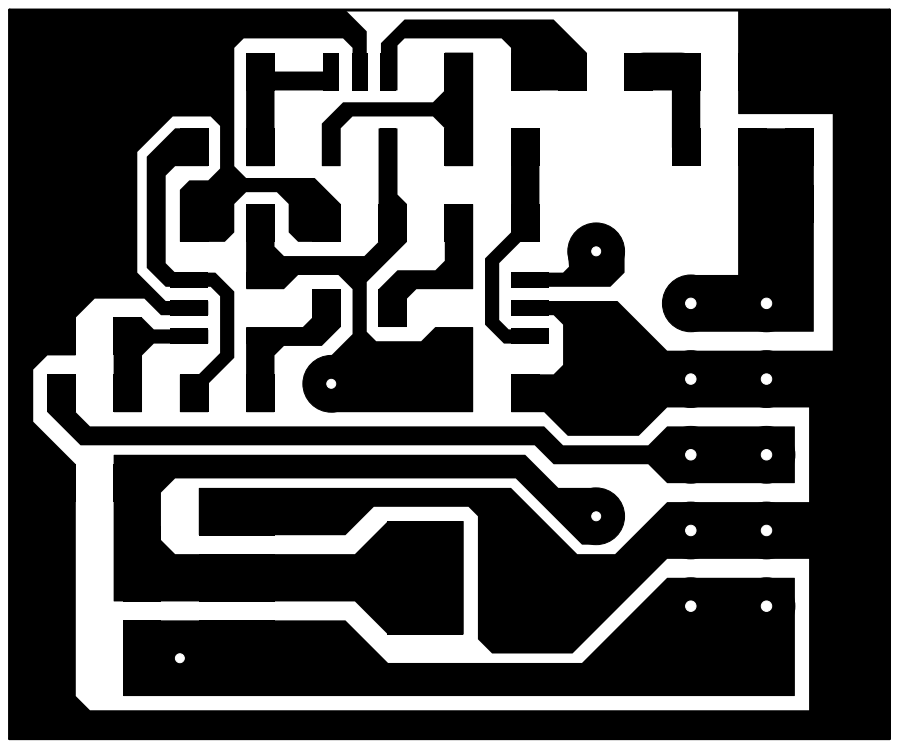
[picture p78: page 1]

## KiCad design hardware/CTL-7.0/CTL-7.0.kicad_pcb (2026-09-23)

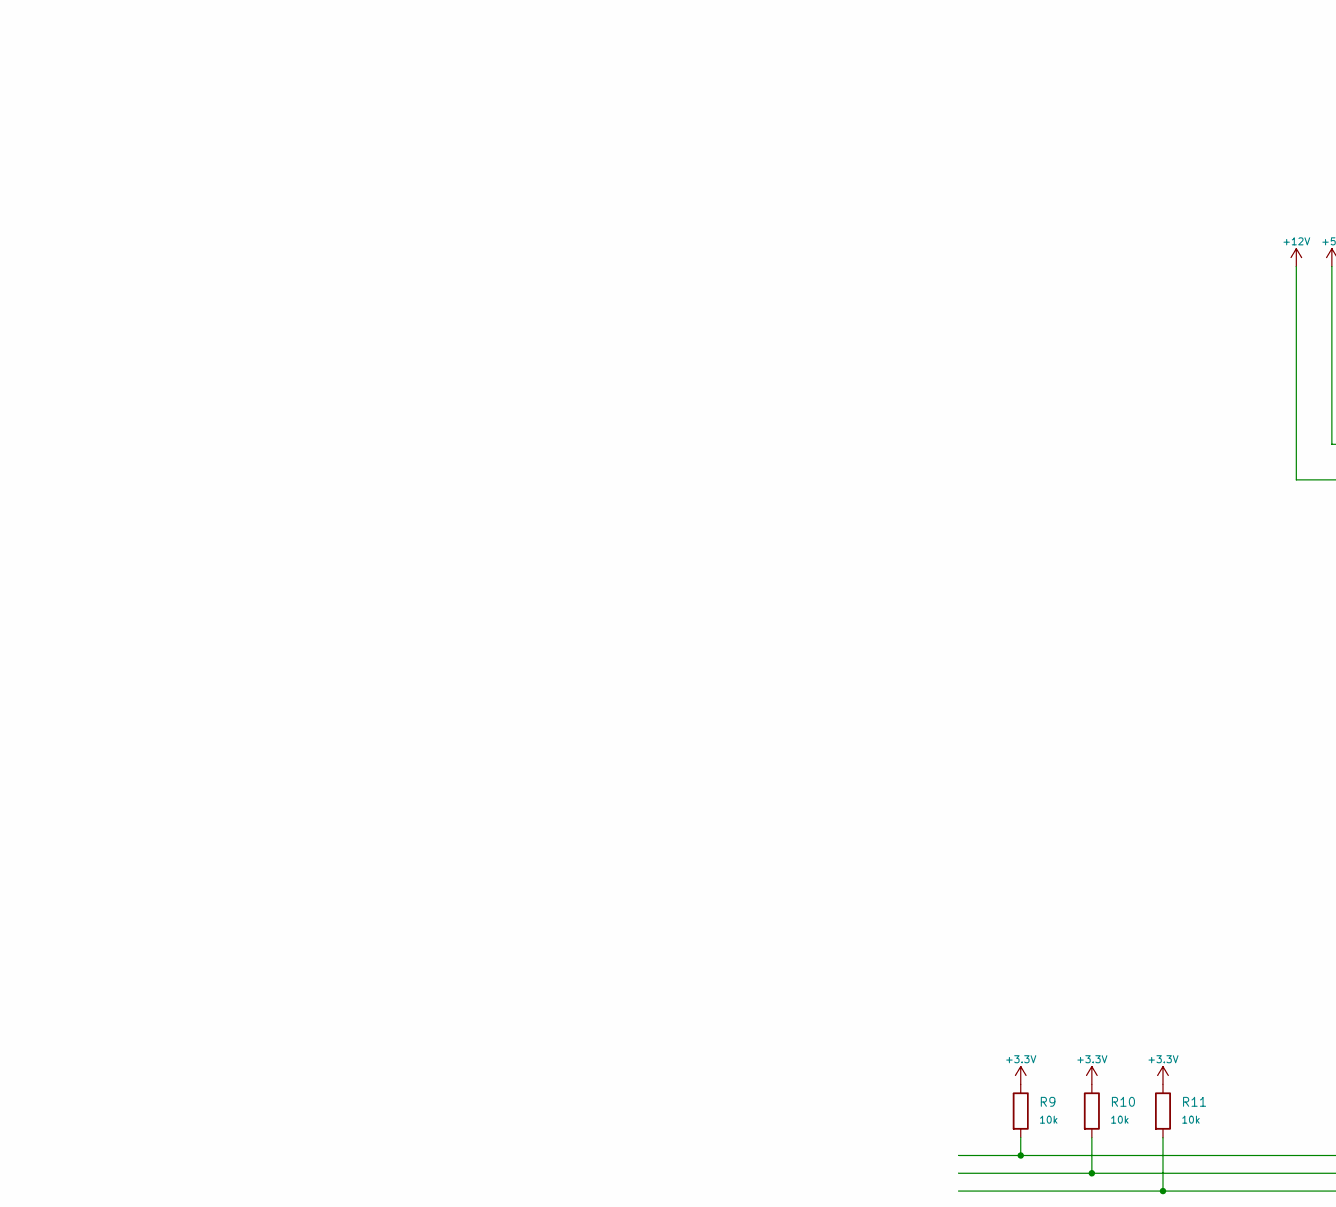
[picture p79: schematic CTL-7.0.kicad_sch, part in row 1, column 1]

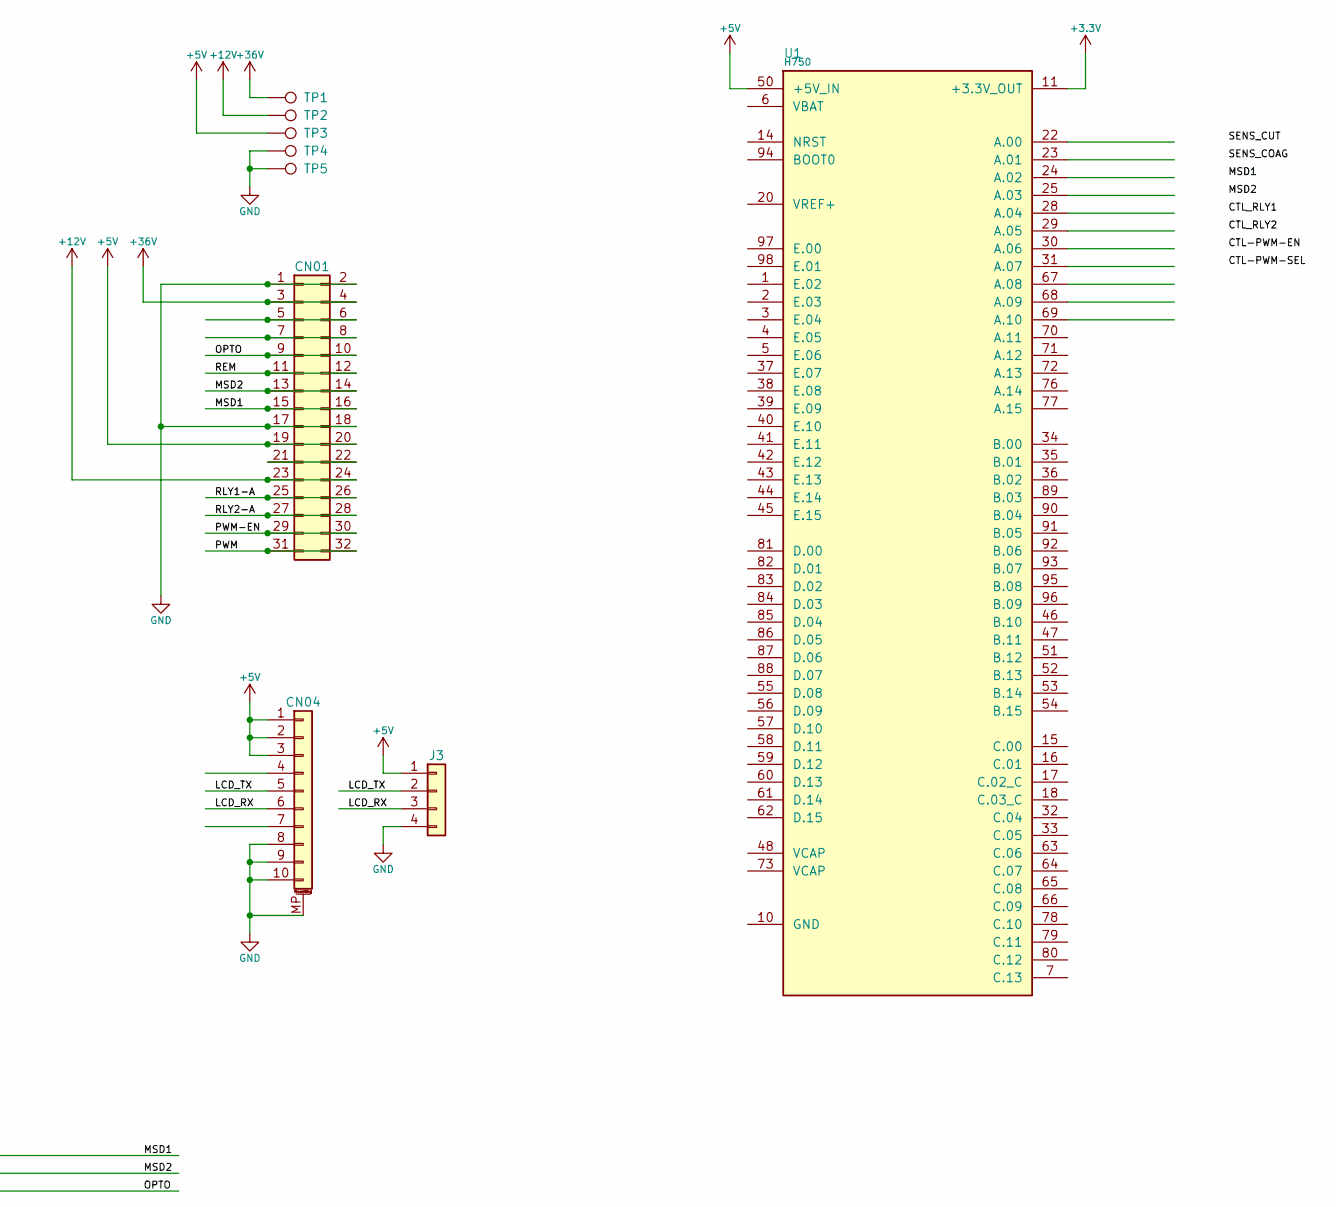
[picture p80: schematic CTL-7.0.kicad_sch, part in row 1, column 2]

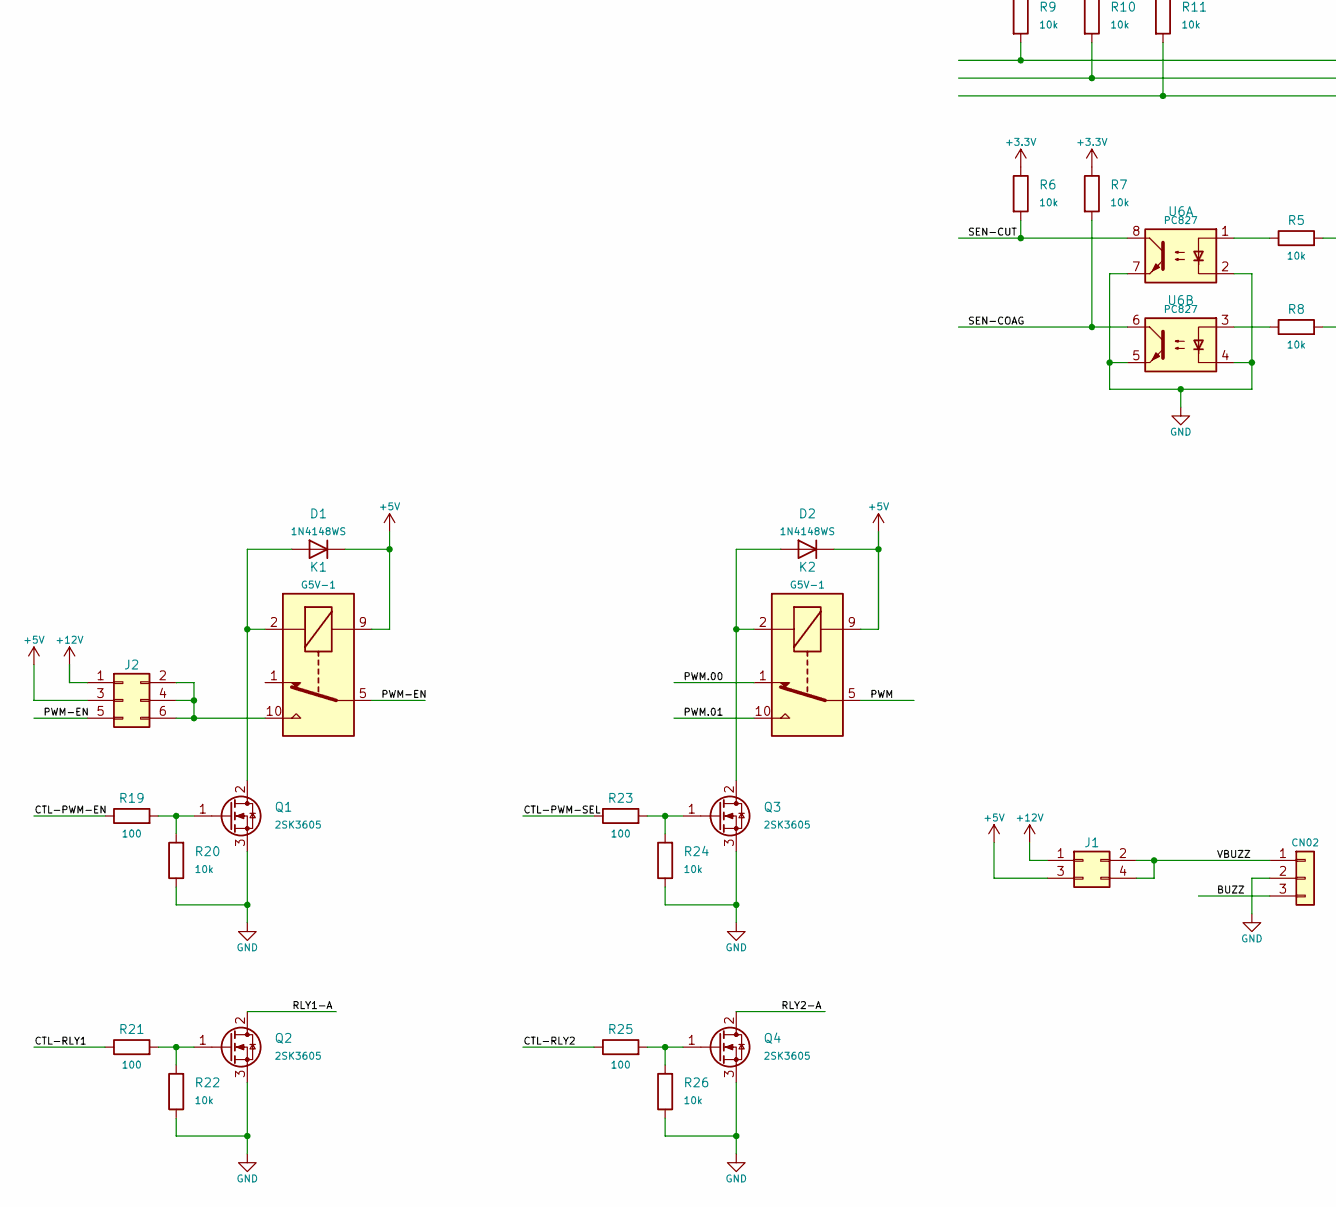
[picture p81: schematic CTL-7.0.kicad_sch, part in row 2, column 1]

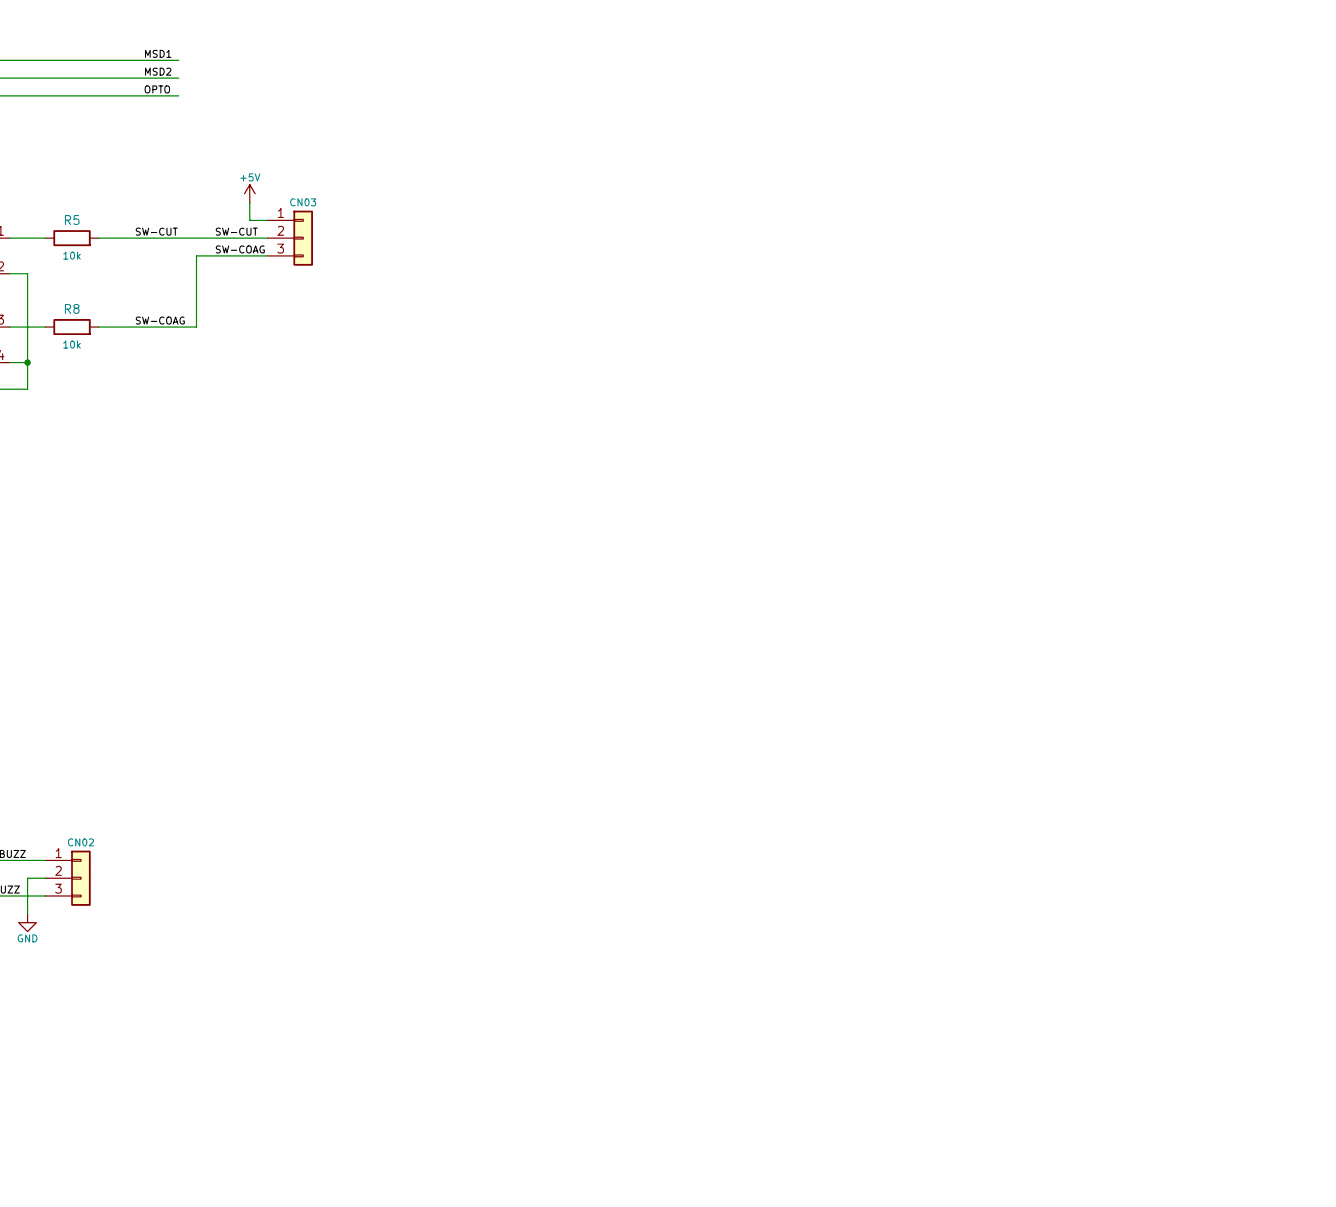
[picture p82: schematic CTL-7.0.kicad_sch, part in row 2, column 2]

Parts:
CN01: Conn_02x16_Odd_Even; PinHeader_2x16_P2.54mm_Vertical
CN02, CN03: Conn_01x03; JST_XH_B3B-XH-A_1x03_P2.50mm_Vertical
CN04: TE_1-84952-0_1x10-1MP_P1.0mm_Horizontal
D1, D2: 1N4148WS; D_SOD-323
J1: Conn_02x02_Odd_Even; PinHeader_2x02_P2.54mm_Vertical_SMD
J2: Conn_02x03_Odd_Even; PinHeader_2x03_P2.54mm_Vertical_SMD
J3: Conn_01x04; PinHeader_1x04_P2.54mm_Vertical
K1, K2: G5V-1; Relay_SPDT_Omron_G5V-1
Q1, Q2, Q3, Q4: 2SK3605; SOT-89-3
R5, R6, R7, R8, R9, R10, R11, R20, R22, R24, R26: 10k; R_0805_2012Metric
R19, R21, R23, R25: 100; R_0805_2012Metric
TP1, TP2, TP3, TP4, TP5: TestPoint; TestPoint_THTPad_2.2225x2.2225mm_Drill1.5mm
U1: H750; STM32H750_v1
U6: PC827; DIP-8_W7.62mm_Socket

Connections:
+3.3V: R6.1, R7.1, R9.1, R10.1, R11.1, U1.11 (+3.3V_OUT), U1.27 (+3.3V_OUT), U1.75 (+3.3V_OUT), U1.100 (+3.3V_OUT)
+5V: CN01.19, CN01.20, CN03.1, CN04.1, CN04.2, CN04.3, D1.1 (K), D2.1 (K), J1.3, J2.3, J3.1, K1.9, K2.9, TP3.1 (1_1), U1.50 (+5V_IN)
+12V: CN01.23, CN01.24, J1.1, J2.1, TP2.1 (1_1)
+36V: CN01.3, CN01.4, TP1.1 (1_1)
/BUZZ: CN02.3
/CTL-PWM-EN: R19.1
/CTL-PWM-SEL: R23.1
/CTL-RLY1: R21.1
/CTL-RLY2: R25.1
/LCD_RX: CN04.6, J3.3
/LCD_TX: CN04.5, J3.2
/MSD1: CN01.15, CN01.16, R9.2
/MSD2: CN01.13, CN01.14, R10.2
/OPTO: CN01.9, CN01.10, R11.2
/PWM: CN01.31, CN01.32, K2.5, K2.6
/PWM-EN: CN01.29, CN01.30, J2.5, K1.5, K1.6
/PWM.00: K2.1
/PWM.01: K2.10
/REM: CN01.11, CN01.12
/RLY1-A: CN01.25, CN01.26, Q2.2 (D)
/RLY2-A: CN01.27, CN01.28, Q4.2 (D)
/SEN-COAG: R7.2, U6.6
/SEN-CUT: R6.2, U6.8
/SW-COAG: CN03.3, R8.2
/SW-CUT: CN03.2, R5.2
/VBUZZ: CN02.1, J1.2, J1.4
unnamed: CN01.5, CN01.6
unnamed: CN01.7, CN01.8
unnamed: CN01.21, CN01.22
unnamed: D1.2 (A), K1.2, Q1.2 (D)
unnamed: D2.2 (A), K2.2, Q3.2 (D)
unnamed: J2.2, J2.4, J2.6, K1.10
unnamed: Q1.1 (G), R19.2, R20.2
unnamed: Q2.1 (G), R21.2, R22.2
unnamed: Q3.1 (G), R23.2, R24.2
unnamed: Q4.1 (G), R25.2, R26.2
unnamed: R5.1, U6.1
unnamed: R8.1, U6.3

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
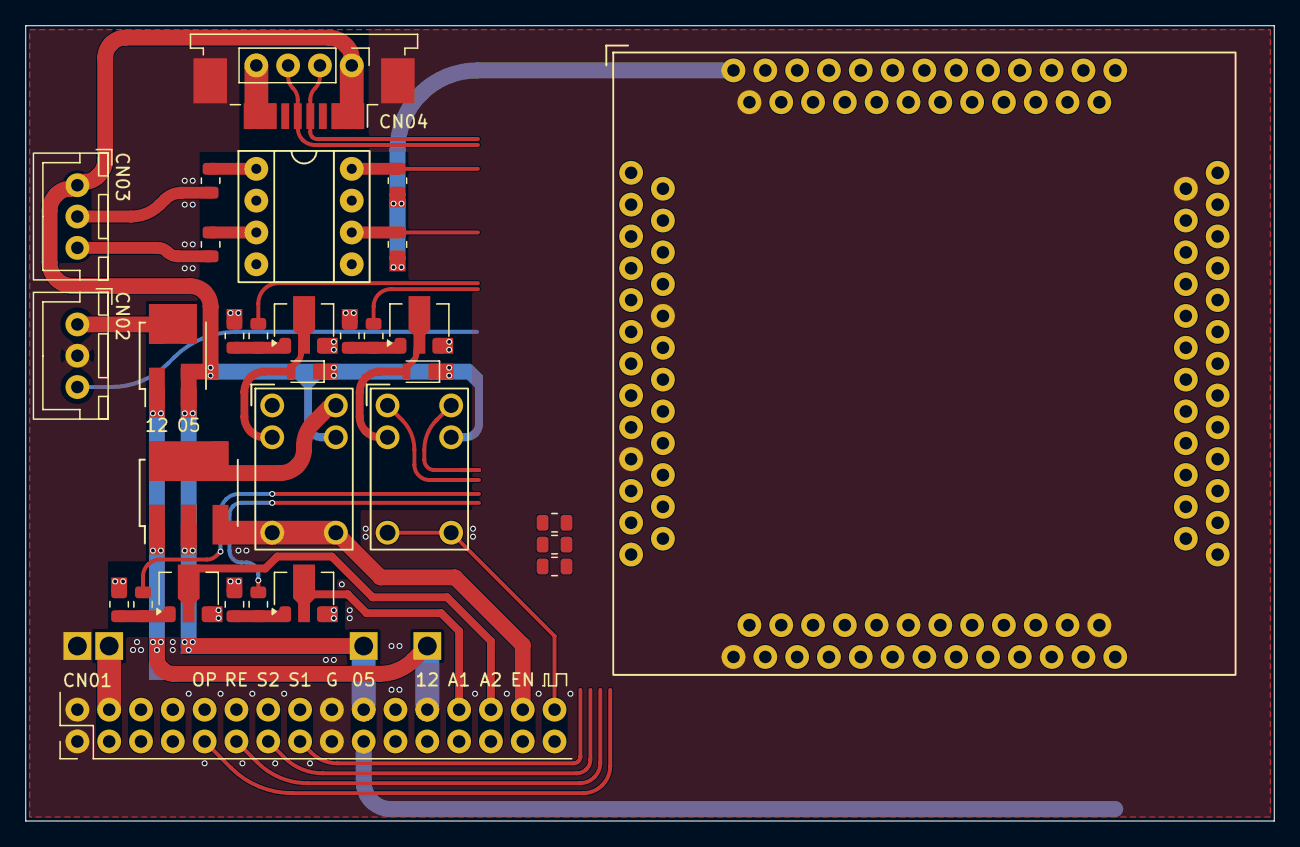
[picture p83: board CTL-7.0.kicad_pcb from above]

Board: 2 copper layers, 99.7 x 63.5 mm, 36 parts (0 on the bottom side), 32 nets.

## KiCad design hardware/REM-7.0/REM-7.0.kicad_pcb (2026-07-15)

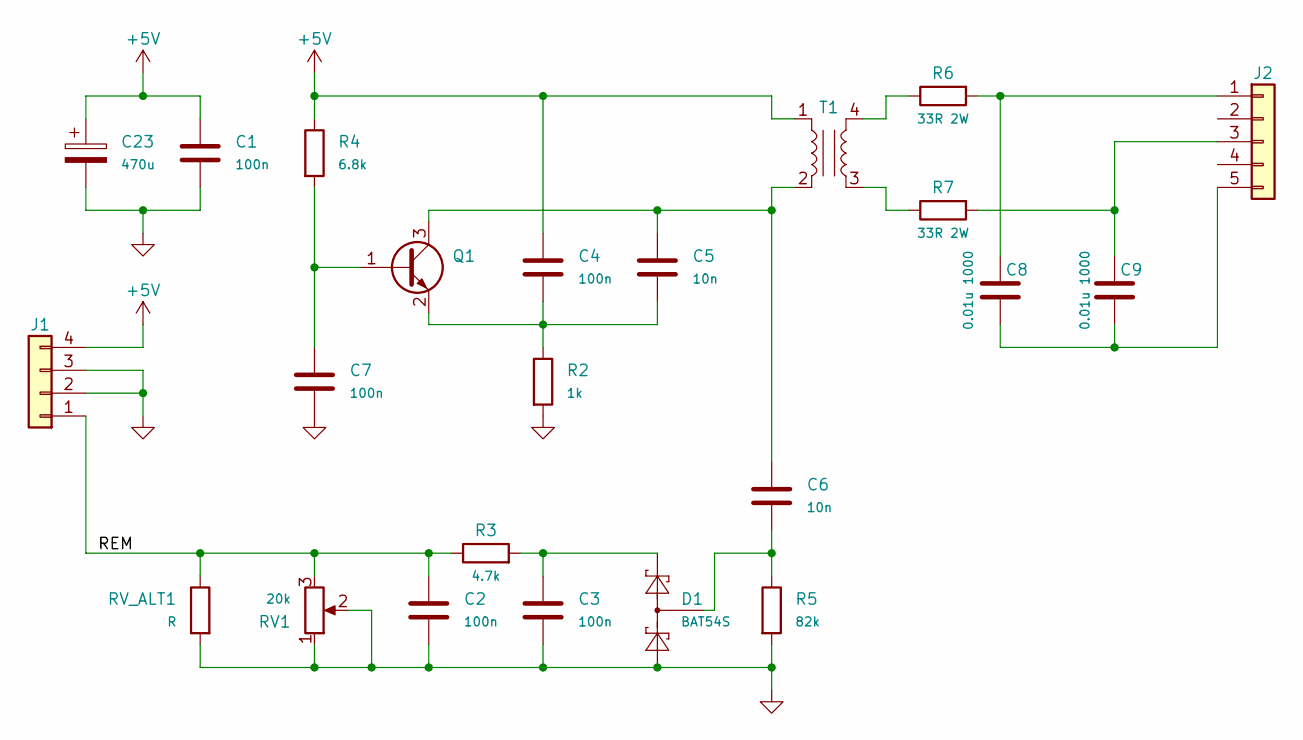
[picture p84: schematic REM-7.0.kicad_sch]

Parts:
C1, C2, C3, C4, C7: 100n; C_0805_2012Metric_Pad1.18x1.45mm_HandSolder
C5, C6: 10n; C_0805_2012Metric_Pad1.18x1.45mm_HandSolder
C8, C9: 0.01u 1000; C_Rect_L13.0mm_W5.0mm_P10.00mm_FKS3_FKP3_MKS4
C23: 470u; CP_EIA-7343-15_Kemet-W_HandSolder
D1: BAT54S; SOT-23
J1: Conn_01x04; PinHeader_1x04_P2.54mm_Horizontal
J2: Conn_01x05; PinHeader_1x05_P2.54mm_Horizontal
Q1: MMBT3904; SOT-23
R2: 1k; R_0805_2012Metric_Pad1.20x1.40mm_HandSolder
R3: 4.7k; R_0805_2012Metric_Pad1.20x1.40mm_HandSolder
R4: 6.8k; R_0805_2012Metric_Pad1.20x1.40mm_HandSolder
R5: 82k; R_0805_2012Metric_Pad1.20x1.40mm_HandSolder
R6, R7: 33R 2W; R_Axial_DIN0414_L11.9mm_D4.5mm_P20.32mm_Horizontal
RV1: 20k; Potentiometer_Bourns_3296W_Vertical
RV_ALT1: R; R_0805_2012Metric_Pad1.20x1.40mm_HandSolder
T1: Transformer_1P_1S; Transformer_EP13_1423

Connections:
+5V: C1.1, C4.1, C23.1, J1.4, R4.1, T1.1 (AA)
/REM: C2.1, J1.1, R3.1, RV1.3, RV_ALT1.1
GND: C1.2, C2.2, C3.2, C7.2, C23.2, D1.1 (A), J1.2, J1.3, R2.2, R5.2, RV1.1, RV1.2, RV_ALT1.2
unnamed: C6.2, D1.3 (COM), R5.1
unnamed: C3.1, D1.2 (K), R3.2
unnamed: C8.1, J2.1, R6.2
unnamed: C9.1, J2.3, R7.2
unnamed: C8.2, C9.2, J2.5
unnamed: C7.1, Q1.1 (B), R4.2
unnamed: C5.1, C6.1, Q1.3 (C), T1.2 (AB)
unnamed: C4.2, C5.2, Q1.2 (E), R2.1
unnamed: R7.1, T1.3 (SA)
unnamed: R6.1, T1.4 (SB)

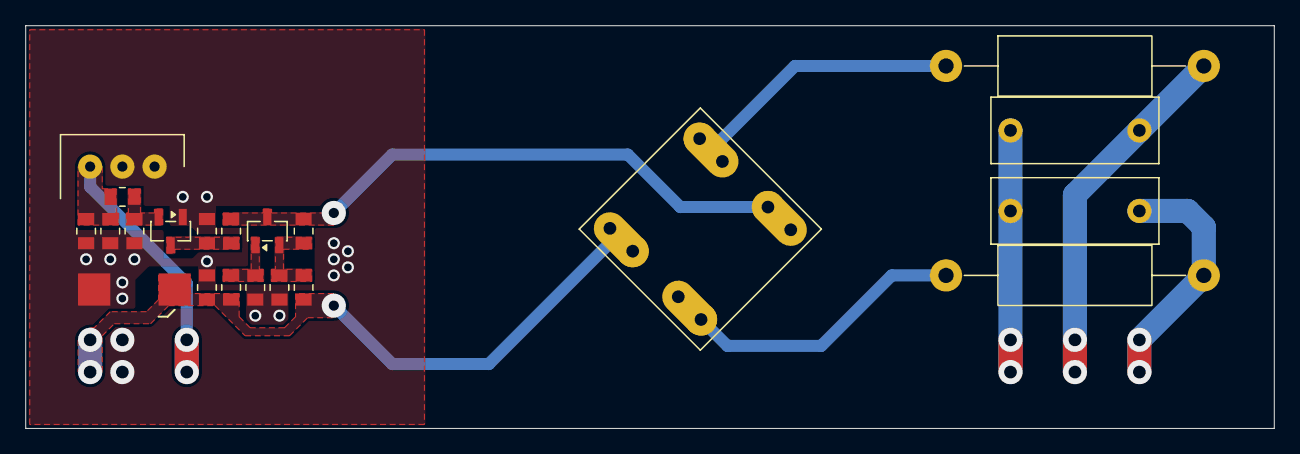
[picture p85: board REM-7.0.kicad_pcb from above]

Board: 2 copper layers, 98.4 x 31.8 mm, 21 parts (0 on the bottom side), 13 nets.

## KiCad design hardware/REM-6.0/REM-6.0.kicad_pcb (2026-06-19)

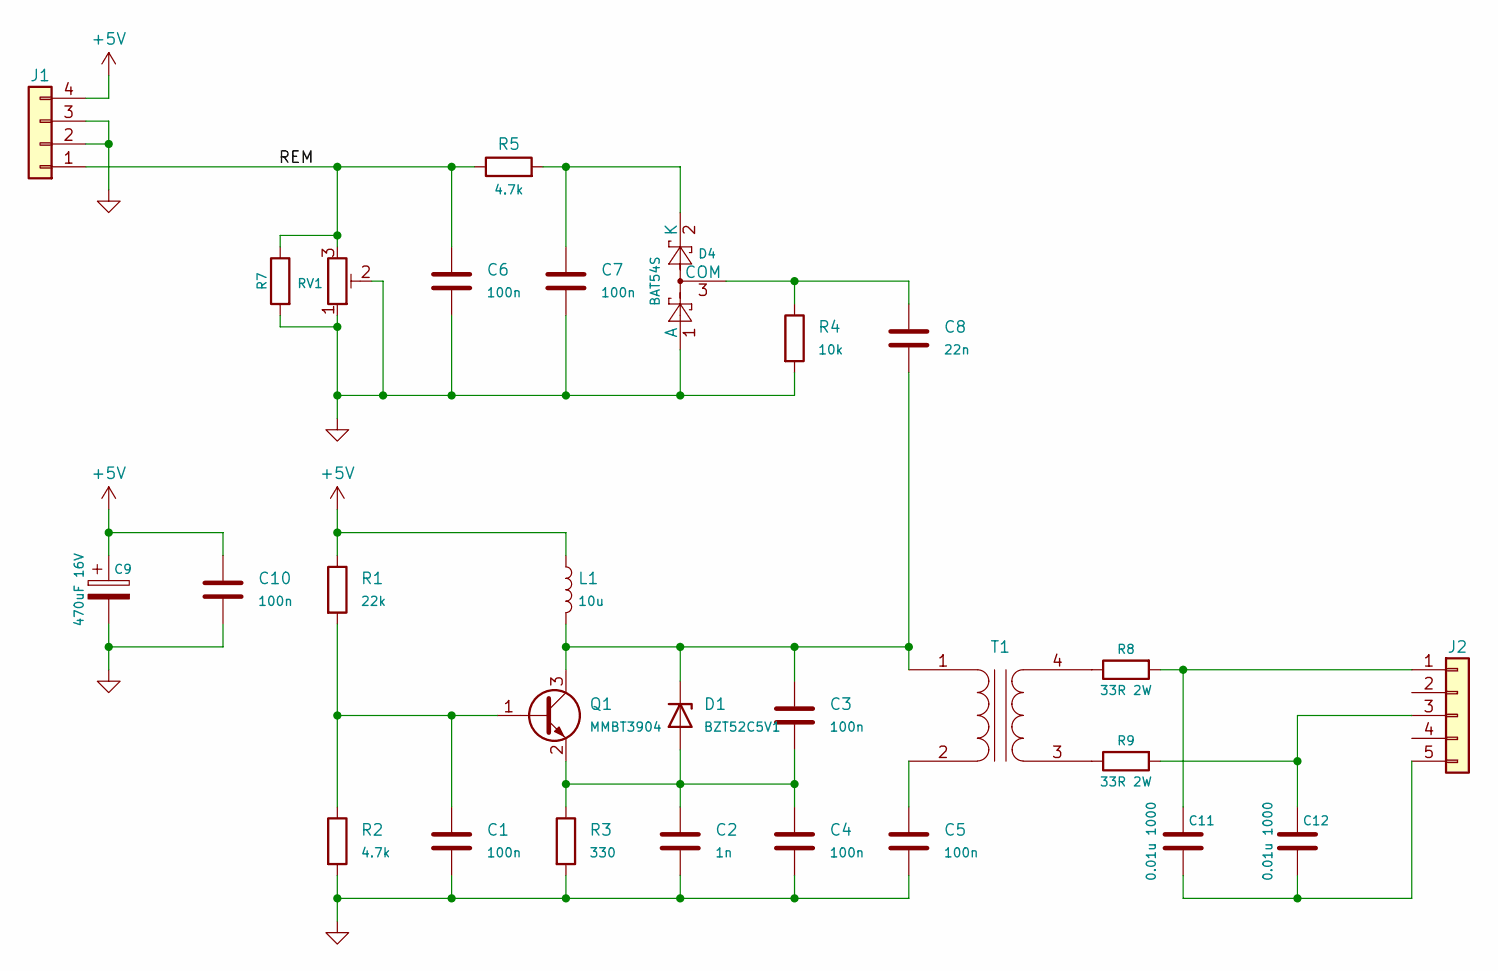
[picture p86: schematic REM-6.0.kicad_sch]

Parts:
C1, C3, C4, C5, C6, C7, C10: 100n; C_0805_2012Metric_Pad1.18x1.45mm_HandSolder
C2: 1n; C_0805_2012Metric_Pad1.18x1.45mm_HandSolder
C8: 22n; C_0805_2012Metric_Pad1.18x1.45mm_HandSolder
C9: 470uF 16V; CP_EIA-7343-15_Kemet-W_HandSolder
C11, C12: 0.01u 1000; C_Rect_L13.0mm_W5.0mm_P10.00mm_FKS3_FKP3_MKS4
D1: BZT52C5V1; D_SOD-123
D4: BAT54S; SOT-23
J1: PinHeader_2.54mm 02x04 Horizontal; PinHeader_1x04_P2.54mm_Horizontal
J2: Conn_01x05; PinHeader_1x05_P2.54mm_Horizontal
L1: 10u; L_10.4x10.4_H4.8
Q1: MMBT3904; SOT-23
R1: 22k; R_0805_2012Metric_Pad1.20x1.40mm_HandSolder
R2, R5: 4.7k; R_0805_2012Metric_Pad1.20x1.40mm_HandSolder
R3: 330; R_0805_2012Metric_Pad1.20x1.40mm_HandSolder
R4: 10k; R_0805_2012Metric_Pad1.20x1.40mm_HandSolder
R7: R_0805_2012Metric_Pad1.20x1.40mm_HandSolder
R8, R9: 33R 2W; R_Axial_DIN0414_L11.9mm_D4.5mm_P20.32mm_Horizontal
RV1: 5kΩ; Potentiometer_Bourns_3296W_Vertical
T1: Transformer_1P_1S; Transformer_Toroid_Horizontal_OD23.5mm_ID13.5mm

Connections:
+5V: C9.1, C10.1, J1.4, L1.1, R1.1
/REM: C6.1, J1.1, R5.1, R7.1, RV1.3
GND: C1.2, C2.2, C4.2, C5.2, C6.2, C7.2, C9.2, C10.2, D4.1 (A), J1.2, J1.3, R2.2, R3.2, R4.2, R7.2, RV1.1, RV1.2
unnamed: C2.1, C3.2, C4.1, D1.2 (A), Q1.2 (E), R3.1
unnamed: C3.1, C8.2, D1.1 (K), L1.2, Q1.3 (C), T1.1 (AA)
unnamed: C8.1, D4.3 (COM), R4.1
unnamed: C7.1, D4.2 (K), R5.2
unnamed: C11.1, J2.1, R8.2
unnamed: C12.1, J2.3, R9.2
unnamed: C11.2, C12.2, J2.5
unnamed: C1.1, Q1.1 (B), R1.2, R2.1
unnamed: C5.1, T1.2 (AB)
unnamed: R9.1, T1.3 (SA)
unnamed: R8.1, T1.4 (SB)

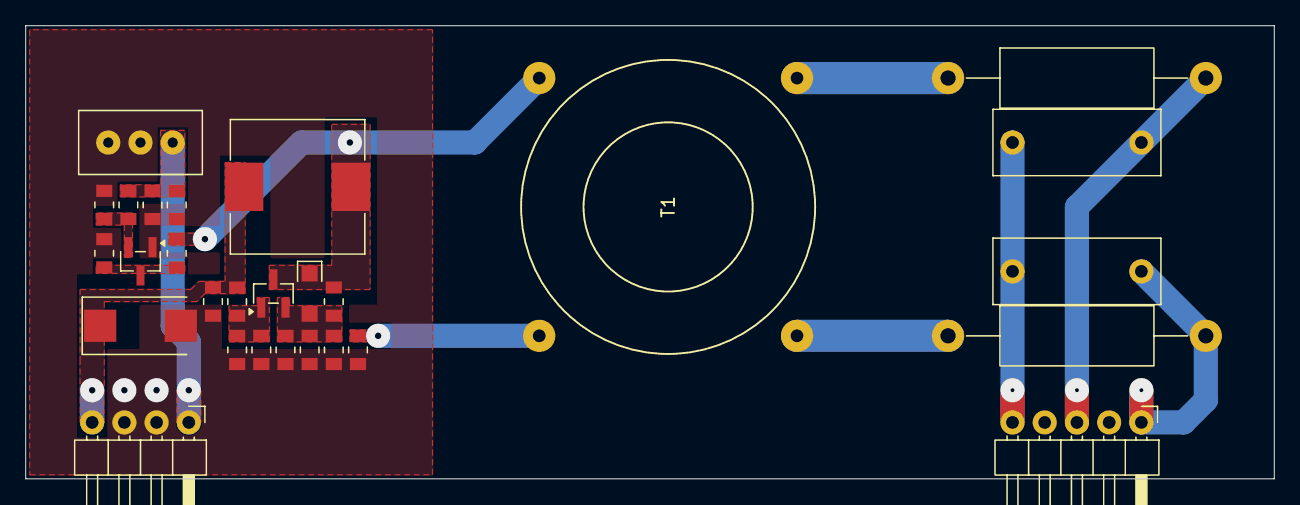
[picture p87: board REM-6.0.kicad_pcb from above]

Board: 2 copper layers, 98.4 x 35.7 mm, 28 parts (0 on the bottom side), 14 nets.

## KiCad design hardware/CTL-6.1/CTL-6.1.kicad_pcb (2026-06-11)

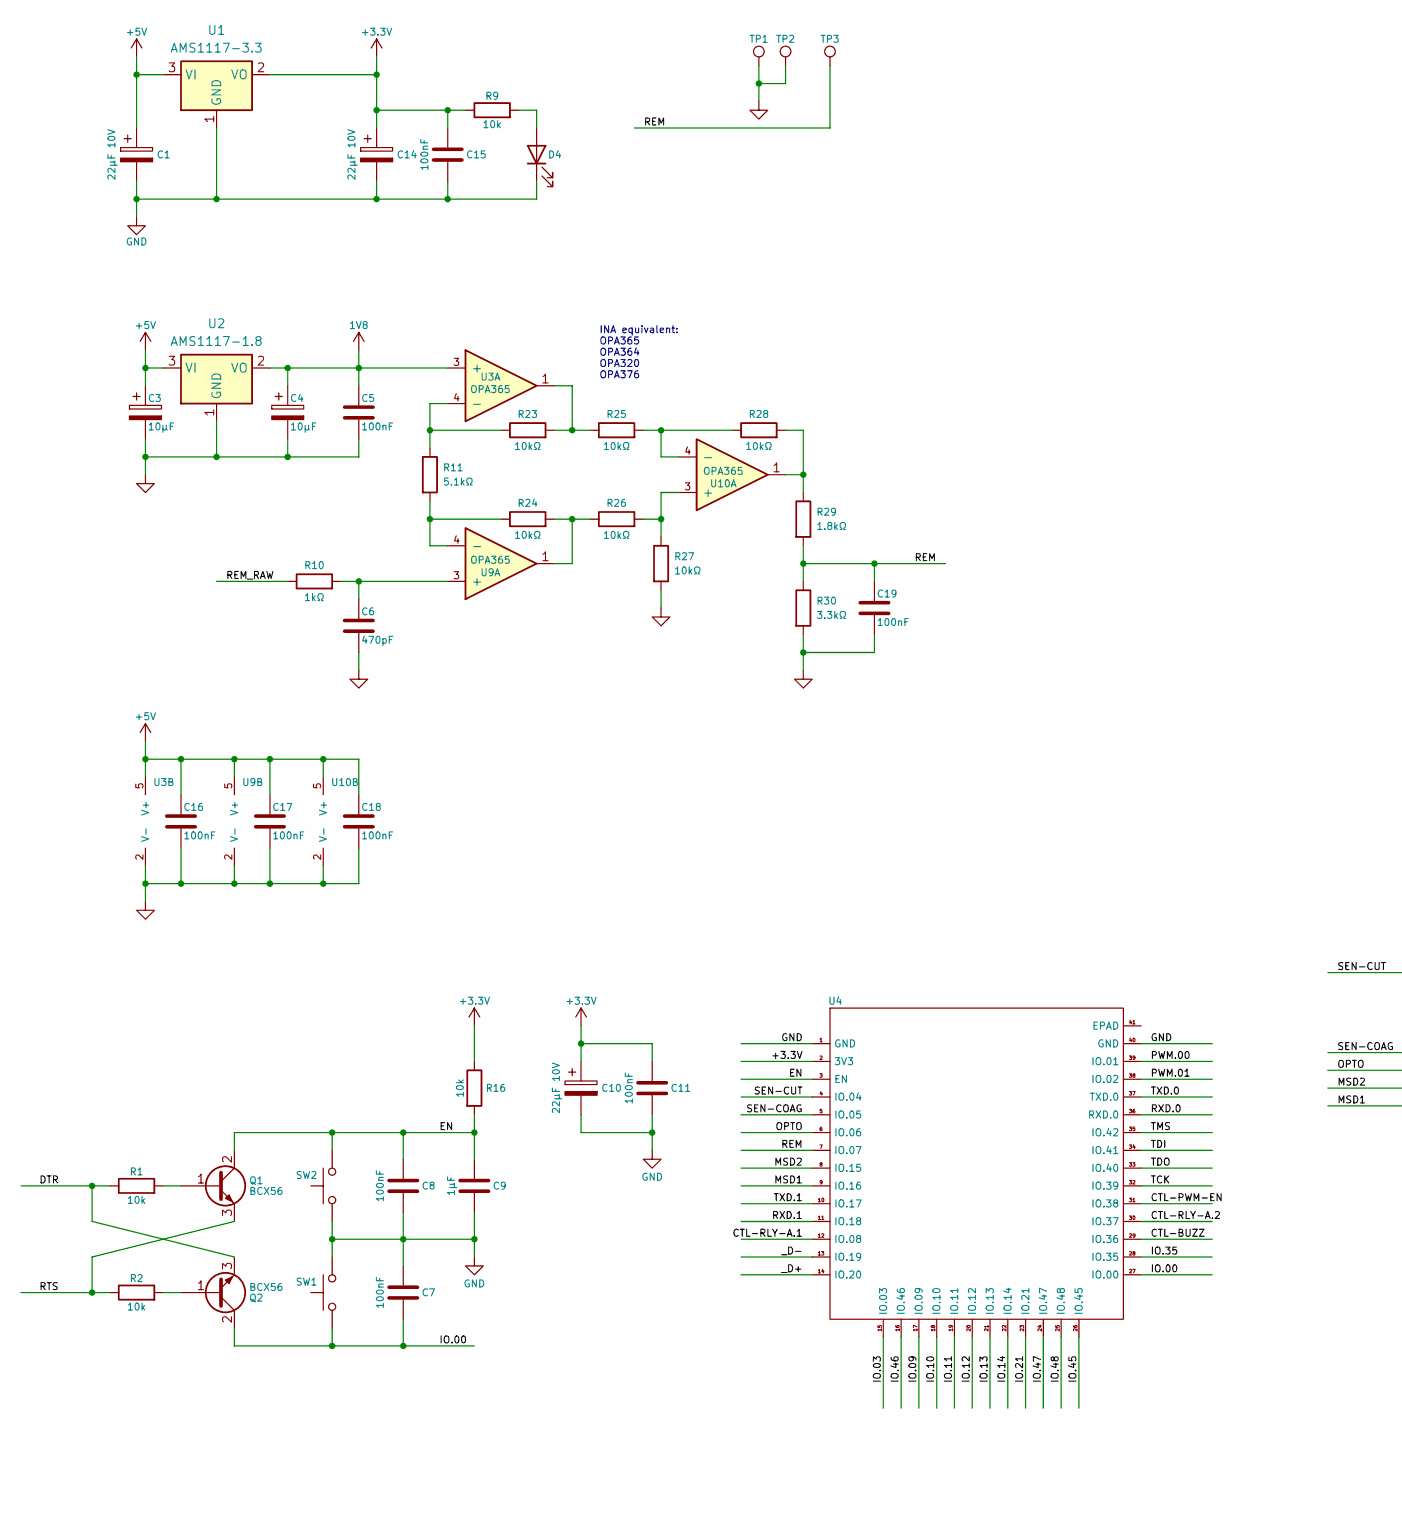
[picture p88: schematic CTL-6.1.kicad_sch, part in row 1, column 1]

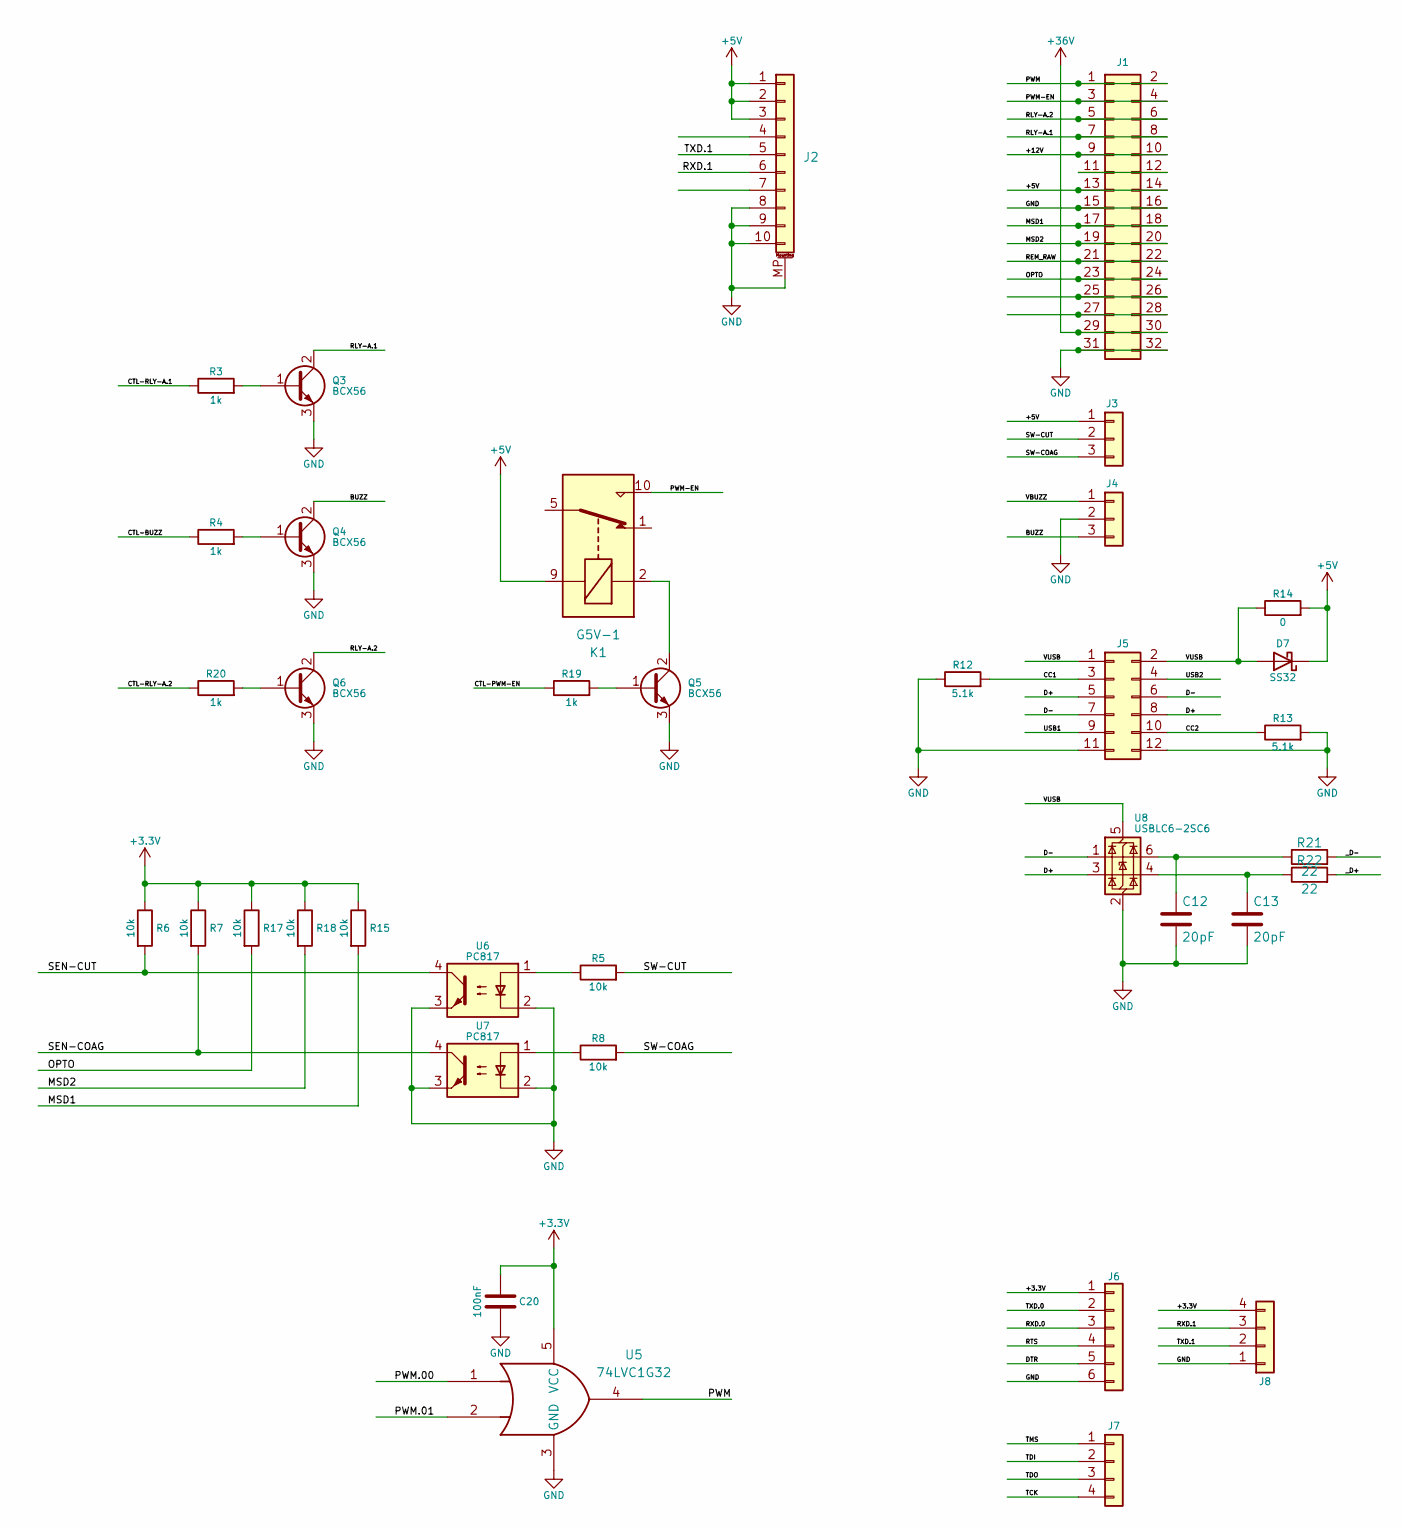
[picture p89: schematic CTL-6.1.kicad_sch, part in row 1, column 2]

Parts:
C1, C10, C14: 22µF 10V; CP_EIA-3216-18_Kemet-A_Pad1.58x1.35mm_HandSolder
C3, C4: 10µF; CP_EIA-3216-18_Kemet-A_Pad1.58x1.35mm_HandSolder
C5, C7, C8, C11, C15, C16, C17, C18, C19, C20: 100nF; C_0805_2012Metric_Pad1.18x1.45mm_HandSolder
C6: 470pF; C_0805_2012Metric_Pad1.18x1.45mm_HandSolder
C9: 1µF; C_0805_2012Metric_Pad1.18x1.45mm_HandSolder
C12, C13: 20pF; C_0805_2012Metric_Pad1.18x1.45mm_HandSolder
D4: LED; LED_0805_2012Metric_Pad1.15x1.40mm_HandSolder
D7: SS32; D_SMA
J1: Conn_02x16_Top_Bottom; PinHeader_2x16_P2.54mm_Horizontal_NoPins
J2: TE_1-84952-0_1x10-1MP_P1.0mm_Horizontal
J3, J4: Conn_01x03; JST_XH_B3B-XH-A_1x03_P2.50mm_Vertical
J5: Conn_02x06_Odd_Even; PinHeader_2x06_P2.54mm_Vertical
J6: Conn_01x04; PinHeader_1x06_P2.54mm_Vertical
J7, J8: Conn_01x04; PinHeader_1x04_P2.54mm_Vertical
K1: G5V-1; Relay_SPDT_Omron_G5V-1
Q1, Q2, Q3, Q4, Q5, Q6: BCX56; SOT-89-3
R1, R2, R5, R6, R7, R8, R9, R15, R16, R17, R18: 10k; R_0805_2012Metric_Pad1.20x1.40mm_HandSolder
R3, R4, R19, R20: 1k; R_0805_2012Metric_Pad1.20x1.40mm_HandSolder
R10: 1kΩ; R_0805_2012Metric_Pad1.20x1.40mm_HandSolder
R11: 5.1kΩ; R_0805_2012Metric_Pad1.20x1.40mm_HandSolder
R12, R13: 5.1k; R_0805_2012Metric_Pad1.20x1.40mm_HandSolder
R14: 0; R_1206_3216Metric_Pad1.30x1.75mm_HandSolder
R21, R22: 22; R_0805_2012Metric_Pad1.20x1.40mm_HandSolder
R23, R24, R25, R26, R27, R28: 10kΩ; R_0805_2012Metric_Pad1.20x1.40mm_HandSolder
R29: 1.8kΩ; R_0805_2012Metric_Pad1.20x1.40mm_HandSolder
R30: 3.3kΩ; R_0805_2012Metric_Pad1.20x1.40mm_HandSolder
SW1, SW2: SW_Omron_B3FS; SW_SPST_Omron_B3FS-100xP
TP1, TP2, TP3: TestPoint; TestPoint_Bridge_Pitch2.54mm_Drill1.0mm
U1: AMS1117-3.3; SOT-223-3_TabPin2
U2: AMS1117-1.8; SOT-223-3_TabPin2
U3, U9, U10: OPA365; SOT-23-5_HandSoldering
U4: ESP32-S3-WROOM-1U
U5: 74LVC1G32; SOT-23-5_HandSoldering
U6, U7: PC817; DIP-4_W7.62mm_Socket
U8: USBLC6-2SC6; SOT-23-6

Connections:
1V8: C4.1, C5.1, U2.2 (VO), U3.3 (+)
+3.3V: C10.1, C11.2, C14.1, C15.2, C20.2, J6.1, J8.4, R6.1, R7.1, R9.1, R15.1, R16.1, R17.1, R18.1, U1.2 (VO), U4.2 (3V3), U5.5 (VCC)
+5V: C1.1, C3.1, C16.1, C17.1, C18.1, D7.1 (K), J1.13, J1.14, J2.1, J2.2, J2.3, J3.1, K1.9, R14.2, U1.3 (VI), U2.3 (VI), U3.5 (V+), U9.5 (V+), U10.5 (V+)
+36V: J1.29, J1.30
/+12V: J1.9, J1.10
/BUZZ: J4.3, Q4.2 (C)
/CC1: J5.3, R12.2
/CC2: J5.10, R13.1
/CTL-BUZZ: R4.1, U4.29 (IO.36)
/CTL-PWM-EN: R19.1, U4.31 (IO.38)
/CTL-RLY-A.1: R3.1, U4.12 (IO.08)
/CTL-RLY-A.2: R20.1, U4.30 (IO.37)
/D+: J5.5, J5.8, U8.3 (I/O2)
/D-: J5.6, J5.7, U8.1 (I/O1)
/DTR: J6.5, Q2.3 (E), R1.1
/EN: C8.2, C9.2, Q1.2 (C), R16.2, SW2.2, U4.3 (EN)
/IO.00: C7.2, Q2.2 (C), SW1.1, U4.27 (IO.00)
/IO.03: U4.15 (IO.03)
/IO.09: U4.17 (IO.09)
/IO.10: U4.18 (IO.10)
/IO.11: U4.19 (IO.11)
/IO.12: U4.20 (IO.12)
/IO.13: U4.21 (IO.13)
/IO.14: U4.22 (IO.14)
/IO.21: U4.23 (IO.21)
/IO.35: U4.28 (IO.35)
/IO.45: U4.26 (IO.45)
/IO.46: U4.16 (IO.46)
/IO.47: U4.24 (IO.47)
/IO.48: U4.25 (IO.48)
/MSD1: J1.17, J1.18, R15.2, U4.9 (IO.16)
/MSD2: J1.19, J1.20, R18.2, U4.8 (IO.15)
/OPTO: J1.23, J1.24, R17.2, U4.6 (IO.06)
/PWM: J1.1, J1.2, U5.4
/PWM-EN: J1.3, J1.4, K1.10
/PWM.00: U4.39 (IO.01), U5.1
/PWM.01: U4.38 (IO.02), U5.2
/REM: C19.1, R29.2, R30.1, TP3.1 (1_1), U4.7 (IO.07)
/REM_RAW: J1.21, J1.22, R10.1
/RLY-A.1: J1.7, J1.8, Q3.2 (C)
/RLY-A.2: J1.5, J1.6, Q6.2 (C)
/RTS: J6.4, Q1.3 (E), R2.1
/RXD.0: J6.3, U4.36 (RXD.0)
/RXD.1: J2.6, J8.3, U4.11 (IO.18)
/SEN-COAG: R7.2, U4.5 (IO.05), U7.4
/SEN-CUT: R6.2, U4.4 (IO.04), U6.4
/SW-COAG: J3.3, R8.2
/SW-CUT: J3.2, R5.2
/TCK: J7.4, U4.32 (IO.39)
/TDI: J7.2, U4.34 (IO.41)
/TDO: J7.3, U4.33 (IO.40)
/TMS: J7.1, U4.35 (IO.42)
/TXD.0: J6.2, U4.37 (TXD.0)
/TXD.1: J2.5, J8.2, U4.10 (IO.17)
/USB1: J5.9
/USB2: J5.4
/VBUZZ: J4.1
/VUSB: D7.2 (A), J5.1, J5.2, R14.1, U8.5 (VBUS)
/_D+: R22.2, U4.14 (IO.20)
/_D-: R21.2, U4.13 (IO.19)
GND: C1.2, C3.2, C4.2, C5.2, C6.2, C7.1, C8.1, C9.1, C10.2, C11.1, C12.2, C13.2, C14.2, C15.1, C16.2, C17.2, C18.2, C19.2, C20.1, D4.1 (K), J1.15, J1.16, J1.31, J1.32, J2.8, J2.9, J2.10, J2.MP (MountPin), J4.2, J5.11, J5.12, J6.6, J8.1, Q3.3 (E), Q4.3 (E), Q5.3 (E), Q6.3 (E), R12.1, R13.2, R27.2, R30.2, SW1.2, SW2.1, TP1.1 (1_1), TP2.1 (1_1), U1.1 (GND), U2.1 (GND), U3.2 (V-), U4.1 (GND), U4.40 (GND), U5.3 (GND), U6.2, U6.3, U7.2, U7.3, U8.2 (GND), U9.2 (V-), U10.2 (V-)
unnamed: C12.1, R21.1, U8.6 (I/O1)
unnamed: C13.1, R22.1, U8.4 (I/O2)
unnamed: D4.2 (A), R9.2
unnamed: J1.11, J1.12
unnamed: J1.25, J1.26
unnamed: J1.27, J1.28
unnamed: K1.5, K1.6
unnamed: Q1.1 (B), R1.2
unnamed: Q2.1 (B), R2.2
unnamed: Q3.1 (B), R3.2
unnamed: Q4.1 (B), R4.2
unnamed: Q5.1 (B), R19.2
unnamed: K1.2, Q5.2 (C)
unnamed: Q6.1 (B), R20.2
unnamed: R5.1, U6.1
unnamed: R8.1, U7.1
unnamed: R23.2, R25.1, U3.1
unnamed: R24.2, R26.1, U9.1
unnamed: R28.2, R29.1, U10.1
unnamed: R11.1, R23.1, U3.4 (-)
unnamed: C6.1, R10.2, U9.3 (+)
unnamed: R11.2, R24.1, U9.4 (-)
unnamed: R26.2, R27.1, U10.3 (+)
unnamed: R25.2, R28.1, U10.4 (-)

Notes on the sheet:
INA equivalent: OPA365 OPA364 OPA320 OPA376

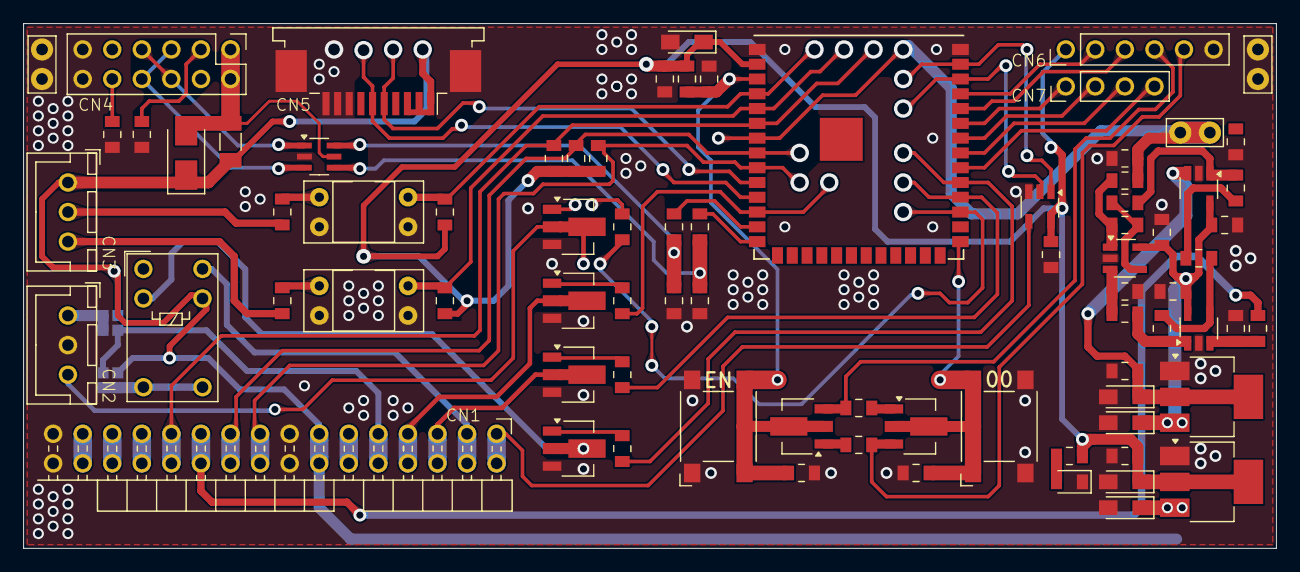
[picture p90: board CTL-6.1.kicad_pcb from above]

Board: 2 copper layers, 107.6 x 45.1 mm, 80 parts (0 on the bottom side), 69 nets.

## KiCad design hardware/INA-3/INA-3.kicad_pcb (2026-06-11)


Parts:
C1, C2, C3, C6, C7, C8, C9: 100nF; C_0805_2012Metric_Pad1.18x1.45mm_HandSolder
C4, C5: 10µF; CP_EIA-3528-12_Kemet-T_Pad1.50x2.35mm_HandSolder
J1: Conn_01x05; PinHeader_1x05_P2.54mm_Horizontal_2
R1: 5.1kΩ; R_0805_2012Metric_Pad1.20x1.40mm_HandSolder
R2, R3, R4, R5, R6, R7, R9, R10, R11: 10kΩ; R_0805_2012Metric_Pad1.20x1.40mm_HandSolder
R8: 1kΩ; R_0805_2012Metric_Pad1.20x1.40mm_HandSolder
U1, U2, U3: OPA365; SOT-23-5_HandSoldering
U4: AMS1117-1.8; SOT-223-3_TabPin2

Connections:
+5V: C1.1, C2.1, C3.1, C4.1, J1.5, U1.5 (V+), U2.5 (V+), U3.5 (V+), U4.3 (VI)
/IN: J1.3, R8.1
/OUT: C9.1, J1.1, R10.2, R11.1
GND: C1.2, C2.2, C3.2, C4.2, C5.2, C6.2, C7.2, C8.2, C9.2, J1.2, J1.4, R7.2, R11.2, U1.2 (V-), U2.2 (V-), U3.2 (V-), U4.1 (GND)
unnamed: C8.1, R9.2, R10.1
unnamed: R2.2, R4.1, U1.1
unnamed: R3.2, R5.1, U2.1
unnamed: R6.2, R9.1, U3.1
unnamed: C5.1, C6.1, U1.3 (+), U4.2 (VO)
unnamed: R1.1, R2.1, U1.4 (-)
unnamed: C7.1, R8.2, U2.3 (+)
unnamed: R1.2, R3.1, U2.4 (-)
unnamed: R5.2, R7.1, U3.3 (+)
unnamed: R4.2, R6.1, U3.4 (-)


Board: 2 copper layers, 29.5 x 24.4 mm, 25 parts (0 on the bottom side), 14 nets.

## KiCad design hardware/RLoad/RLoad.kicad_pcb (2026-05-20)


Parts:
R1, R2, R3, R4, R5, R6, R7, R8, R9, R10, R11, R12, R13, R14, R15, R16, R17, R18, R19, R20, R21, R22, R23, R24, R25, R26, R27, R28, R29, R30, R31, R32, R33, R34, R35, R36, R37, R38, R39, R40, R41, R42, R43, R44, R45, R46, R47, R48, R49, R50, R51, R52, R53, R54, R55, R56, R57, R58, R59, R60, R61, R62, R63, R64, R65, R66, R67, R68, R69, R70, R71, R72, R73, R74, R75, R76, R77, R78, R79, R80, R81, R82, R83, R84, R85, R86, R87, R88, R89, R90, R91, R92, R93, R94, R95, R96, R97, R98, R99, R100: R; R_Axial_DIN0414_L11.9mm_D4.5mm_P15.24mm_Horizontal

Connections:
/+: R1.1, R11.1, R21.1, R31.1, R41.1, R51.1, R61.1, R71.1, R81.1, R91.1
/-: R10.2, R20.2, R30.2, R40.2, R50.2, R60.2, R70.2, R80.2, R90.2, R100.2
unnamed: R1.2, R2.1
unnamed: R2.2, R3.1
unnamed: R3.2, R4.1
unnamed: R4.2, R5.1
unnamed: R5.2, R6.1
unnamed: R6.2, R7.1
unnamed: R7.2, R8.1
unnamed: R8.2, R9.1
unnamed: R9.2, R10.1
unnamed: R11.2, R12.1
unnamed: R12.2, R13.1
unnamed: R13.2, R14.1
unnamed: R14.2, R15.1
unnamed: R15.2, R16.1
unnamed: R16.2, R17.1
unnamed: R17.2, R18.1
unnamed: R18.2, R19.1
unnamed: R19.2, R20.1
unnamed: R21.2, R22.1
unnamed: R22.2, R23.1
unnamed: R23.2, R24.1
unnamed: R24.2, R25.1
unnamed: R25.2, R26.1
unnamed: R26.2, R27.1
unnamed: R27.2, R28.1
unnamed: R28.2, R29.1
unnamed: R29.2, R30.1
unnamed: R31.2, R32.1
unnamed: R32.2, R33.1
unnamed: R33.2, R34.1
unnamed: R34.2, R35.1
unnamed: R35.2, R36.1
unnamed: R36.2, R37.1
unnamed: R37.2, R38.1
unnamed: R38.2, R39.1
unnamed: R39.2, R40.1
unnamed: R41.2, R42.1
unnamed: R42.2, R43.1
unnamed: R43.2, R44.1
unnamed: R44.2, R45.1
unnamed: R45.2, R46.1
unnamed: R46.2, R47.1
unnamed: R47.2, R48.1
unnamed: R48.2, R49.1
unnamed: R49.2, R50.1
unnamed: R51.2, R52.1
unnamed: R52.2, R53.1
unnamed: R53.2, R54.1
unnamed: R54.2, R55.1
unnamed: R55.2, R56.1
unnamed: R56.2, R57.1
unnamed: R57.2, R58.1
unnamed: R58.2, R59.1
unnamed: R59.2, R60.1
unnamed: R61.2, R62.1
unnamed: R62.2, R63.1
unnamed: R63.2, R64.1
unnamed: R64.2, R65.1
unnamed: R65.2, R66.1
unnamed: R66.2, R67.1
unnamed: R67.2, R68.1
unnamed: R68.2, R69.1
unnamed: R69.2, R70.1
unnamed: R71.2, R72.1
unnamed: R72.2, R73.1
unnamed: R73.2, R74.1
unnamed: R74.2, R75.1
unnamed: R75.2, R76.1
unnamed: R76.2, R77.1
unnamed: R77.2, R78.1
unnamed: R78.2, R79.1
unnamed: R79.2, R80.1
unnamed: R81.2, R82.1
unnamed: R82.2, R83.1
unnamed: R83.2, R84.1
unnamed: R84.2, R85.1
unnamed: R85.2, R86.1
unnamed: R86.2, R87.1
unnamed: R87.2, R88.1
unnamed: R88.2, R89.1
unnamed: R89.2, R90.1
unnamed: R91.2, R92.1
unnamed: R92.2, R93.1
unnamed: R93.2, R94.1
unnamed: R94.2, R95.1
unnamed: R95.2, R96.1
unnamed: R96.2, R97.1
unnamed: R97.2, R98.1
unnamed: R98.2, R99.1
unnamed: R99.2, R100.1

Board: 2 copper layers, 100 parts (0 on the bottom side), 92 nets, no tracks yet.

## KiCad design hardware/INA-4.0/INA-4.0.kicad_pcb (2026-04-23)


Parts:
C1, C2, C3: 100nF; C_Rect_L7.2mm_W2.5mm_P5.00mm_FKS2_FKP2_MKS2_MKP2
C4, C5: 10µF; CP_EIA-3528-12_Kemet-T_Pad1.50x2.35mm_HandSolder
C6: 100nF; C_0805_2012Metric_Pad1.18x1.45mm_HandSolder
J1: Conn_01x05; PinHeader_1x06_P2.54mm_Horizontal
R1, R3, R4, R5, R6, R7: 10kΩ; R_Axial_DIN0204_L3.6mm_D1.6mm_P5.08mm_Horizontal
R2: 6.8kΩ; R_Axial_DIN0204_L3.6mm_D1.6mm_P5.08mm_Horizontal
R8: 1kΩ; R_Axial_DIN0204_L3.6mm_D1.6mm_P5.08mm_Horizontal
U1, U2: LM358; DIP-8_W7.62mm_Socket
U3: AMS1117-1.8; SOT-223-3_TabPin2

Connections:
1V8: C5.1, C6.1, U1.3 (+), U3.2 (VO)
+5V: C2.1, C3.1, C4.1, J1.2, J1.6, U1.8 (V+), U2.8 (V+), U3.3 (VI)
/IN: J1.4, R8.1
/OUT: J1.1, R6.2, U2.1
GND: C1.2, C2.2, C3.2, C4.2, C5.2, C6.2, J1.3, J1.5, R7.2, U1.4 (V-), U2.4 (V-), U3.1 (GND)
unnamed: R1.2, R4.1, U1.1
unnamed: R3.2, R5.1, U1.7
unnamed: R1.1, R2.1, U1.2 (-)
unnamed: C1.1, R8.2, U1.5 (+)
unnamed: R2.2, R3.1, U1.6 (-)
unnamed: R5.2, R7.1, U2.3 (+)
unnamed: R4.2, R6.1, U2.2 (-)



Board: 2 copper layers, 36.8 x 38.1 mm, 18 parts (4 on the bottom side), 12 nets.

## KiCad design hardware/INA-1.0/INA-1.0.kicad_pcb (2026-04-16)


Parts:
C1: 0.1µF; C_0805_2012Metric_Pad1.18x1.45mm_HandSolder
C2: 10µF 16V; CP_EIA-3528-12_Kemet-T_Pad1.50x2.35mm_HandSolder
C3, C4: 100nF; C_0805_2012Metric_Pad1.18x1.45mm_HandSolder
C5: 2.2µF; C_0805_2012Metric_Pad1.18x1.45mm_HandSolder
J1: Conn_01x04; PinHeader_1x04_P2.54mm_Horizontal_2
R1: 20kΩ; R_0805_2012Metric_Pad1.20x1.40mm_HandSolder
R2: 1kΩ; R_0805_2012Metric_Pad1.20x1.40mm_HandSolder
U1: AD623; DIP-8_W7.62mm_SMDSocket_SmallPads
U2: MCP1501-12xSN; SOIC-8_3.9x4.9mm_P1.27mm

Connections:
+5V: C1.1, C2.1, C5.1, J1.4, U1.7 (Vs+), U2.1 (VDD), U2.3 (~SHDN)
/INPUT: J1.2, R2.1
/OUTPUT: J1.1, U1.6
GND: C1.2, C2.2, C3.2, C4.2, C5.2, J1.3, U1.4 (Vs-), U1.5 (Ref), U2.2 (GND), U2.4 (GND), U2.5 (GND), U2.6 (GND)
unnamed: R1.1, U1.1 (Rg)
unnamed: R1.2, U1.8 (Rg)
unnamed: C3.1, R2.2, U1.3 (+)
unnamed: C4.1, U1.2 (-), U2.7 (OUT), U2.8 (FB)


Board: 2 copper layers, 25.4 x 25.4 mm, 10 parts (0 on the bottom side), 8 nets.

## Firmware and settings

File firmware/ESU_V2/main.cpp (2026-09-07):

#include "main.h"

extern HRTIM_HandleTypeDef hhrtim1;

// Definisi Konstanta HRTIM DLL Speed Equivalent (~2.5 GHz)
#define HRTIM_PER_400KHZ   6250U   // 2.5 GHz / 400 kHz
#define HRTIM_PER_100KHZ  25000U   // 2.5 GHz / 100 kHz

/**
 * @brief Menghentikan seluruh output PWM secara instan (Keamanan ESU)
 */
void stop_all_outputs(void)
{
  // Disable Burst Mode Controller jika sedang aktif
  HAL_HRTIM_BurstModeStop(&hhrtim1);

  // Stop Timer A & Timer B Output
  HAL_HRTIM_WaveformOutputStop(&hhrtim1, HRTIM_OUTPUT_TA1);
  HAL_HRTIM_WaveformOutputStop(&hhrtim1, HRTIM_OUTPUT_TB1);
  
  HAL_HRTIM_WaveformCountStop(&hhrtim1, HRTIM_TIMER_A);
  HAL_HRTIM_WaveformCountStop(&hhrtim1, HRTIM_TIMER_B);
}

/**
 * @brief Mengkonfigurasi dan mengaktifkan Burst Mode Controller (BMC)
 * @param clock_source: HRTIM_BURSTMODECTRLCLK_TIMA atau HRTIM_BURSTMODECTRLCLK_TIMB
 * @param pulse_on: Jumlah pulsa ON
 * @param pulse_total: Total periode pulsa (ON + OFF)
 */
static void setup_burst_mode(uint32_t clock_source, uint16_t pulse_on, uint16_t pulse_total)
{
  HRTIM_BurstModeCfgTypeDef sBurstModeConfig = {0};

  sBurstModeConfig.Mode = HRTIM_BURSTMODE_CONT;               // Berjalan terus menerus
  sBurstModeConfig.ClockSource = clock_source;                // Menghitung pulsa dari timer terkait
  sBurstModeConfig.Prescaler = HRTIM_BURSTMODEPRESCALER_DIV1;
  sBurstModeConfig.Period = pulse_total;                      // Total siklus pulsa (ON + OFF)
  sBurstModeConfig.Compare = pulse_on;                        // Jumlah pulsa ON

  HAL_HRTIM_BurstModeConfig(&hhrtim1, &sBurstModeConfig);
  HAL_HRTIM_BurstModeStart(&hhrtim1);
}

/**
 * @brief Menjalankan Generator Sinyal ESU berdasarkan mode yang dipilih
 * @param signalType: 0 (400k Cont), 1 (400k 18/2), 2 (400k 17/3), 3 (100k 1/3), 4 (100k 1/4)
 */
void start(uint8_t signalType) 
{
  // 1. Selalu hentikan sinyal aktif sebelumnya demi keamanan alat ESU
  stop_all_outputs();

  if (signalType == 0 || signalType == 1 || signalType == 2) 
  {
    /* ========================================================
       SETUP CHANNEL 0: Pin 1 (HRTIM_OUTPUT_TA1 - 400 kHz)
       ======================================================== */
    
    uint32_t period = HRTIM_PER_400KHZ;
    uint32_t duty_cycle_50pct = period / 2; // Duty cycle carrier 50%

    // Set frekuensi & duty cycle carrier pada Timer A
    __HAL_HRTIM_SET_PERIOD(&hhrtim1, HRTIM_TIMERINDEX_TIMER_A, period);
    __HAL_HRTIM_SET_COMPARE(&hhrtim1, HRTIM_TIMERINDEX_TIMER_A, HRTIM_COMPAREUNIT_1, duty_cycle_50pct);

    if (signalType == 0) 
    {
      // Mode 1: 400 kHz Continuous (Tanpa Modulasi Burst)
      // Cukup jalankan Timer A biasa
    } 
    else if (signalType == 1) 
    {
      // Mode 2: 400 kHz, 18 pulse ON, 2 pulse OFF
      setup_burst_mode(HRTIM_BURSTMODECTRLCLK_TIMA, 18, 20);
    } 
    else if (signalType == 2) 
    {
      // Mode 3: 400 kHz, 17 pulse ON, 3 pulse OFF
      setup_burst_mode(HRTIM_BURSTMODECTRLCLK_TIMA, 17, 20);
    }

    // Start Timer A & Pin TA1 Output
    HAL_HRTIM_WaveformCountStart(&hhrtim1, HRTIM_TIMER_A);
    HAL_HRTIM_WaveformOutputStart(&hhrtim1, HRTIM_OUTPUT_TA1);

  } 
  else if (signalType == 3 || signalType == 4) 
  {
    /* ========================================================
       SETUP CHANNEL 1: Pin 2 (HRTIM_OUTPUT_TB1 - 100 kHz)
       ======================================================== */

    uint32_t period = HRTIM_PER_100KHZ;
    uint32_t duty_cycle_50pct = period / 2; // Duty cycle carrier 50%

    // Set frekuensi & duty cycle carrier pada Timer B
    __HAL_HRTIM_SET_PERIOD(&hhrtim1, HRTIM_TIMERINDEX_TIMER_B, period);
    __HAL_HRTIM_SET_COMPARE(&hhrtim1, HRTIM_TIMERINDEX_TIMER_B, HRTIM_COMPAREUNIT_1, duty_cycle_50pct);

    if (signalType == 3) 
    {
      // Mode 4: 100 kHz, 1 pulse ON, 3 pulse OFF (Total = 4 pulsa)
      setup_burst_mode(HRTIM_BURSTMODECTRLCLK_TIMB, 1, 4);
    } 
    else if (signalType == 4) 
    {
      // Mode 5: 100 kHz, 1 pulse ON, 4 pulse OFF (Total = 5 pulsa)
      setup_burst_mode(HRTIM_BURSTMODECTRLCLK_TIMB, 1, 5);
    }

    // Start Timer B & Pin TB1 Output
    HAL_HRTIM_WaveformCountStart(&hhrtim1, HRTIM_TIMER_B);
    HAL_HRTIM_WaveformOutputStart(&hhrtim1, HRTIM_OUTPUT_TB1);
  }
}

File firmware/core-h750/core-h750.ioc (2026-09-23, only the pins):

Mcu.UserName=STM32H750VBTx
PA5.Signal=GPIO_Output
PC6.Signal=HRTIM_CHA1
PC8.Signal=HRTIM_CHB1

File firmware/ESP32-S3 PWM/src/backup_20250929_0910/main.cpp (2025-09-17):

#include <Arduino.h>
#include <driver/rmt.h>
#include <driver/adc.h>
#include <esp_adc_cal.h>
#include <LittleFS.h>
#include <ArduinoJson.h>

// Include our custom headers
#include "config.h"
#include "data_manager.h"
#include "display_comm.h"
#include "hardware_control.h"

void setup() {
  setupRelay();
  setupADC();

  Serial.begin(115200);
  Serial1.begin(115200, SERIAL_8N1, 18, 17);

  // Initialize LittleFS with proper error handling
  if (!initLittleFS()) {
    Serial.println("LittleFS initialization failed!");
    return;  // Stop execution if LittleFS fails
  }

  rmt_config_t rmt_tx_0;
  rmt_tx_0.channel = RMT_TX_CHANNEL_0;
  rmt_tx_0.gpio_num = PWM_0;
  rmt_tx_0.mem_block_num = 1;
  rmt_tx_0.tx_config.carrier_en = 0;
  rmt_tx_0.tx_config.idle_output_en = true;
  rmt_tx_0.clk_div = 1; // 80 MHz ÷ 1 = 80 MHz
  // rmt_tx_0.tx_config.idle_level = RMT_IDLE_LEVEL_LOW;
  rmt_tx_0.tx_config.loop_en = 1;
  rmt_config(&rmt_tx_0);
  rmt_driver_install(RMT_TX_CHANNEL_0, 0, 0);

  rmt_config_t rmt_tx_1;
  rmt_tx_1.channel = RMT_TX_CHANNEL_1;
  rmt_tx_1.gpio_num = PWM_1;
  rmt_tx_1.mem_block_num = 1;
  rmt_tx_1.tx_config.carrier_en = 0;
  rmt_tx_1.clk_div = 4; // 80 MHz ÷ 4 = 20 MHz
  // rmt_tx_1.tx_config.idle_level = RMT_IDLE_LEVEL_LOW;
  rmt_tx_1.tx_config.idle_output_en = 1;
  rmt_tx_1.tx_config.loop_en = 1;
  rmt_config(&rmt_tx_1);
  rmt_driver_install(RMT_TX_CHANNEL_1, 0, 0);

  rmt_set_tx_intr_en(RMT_TX_CHANNEL_0, 1);
  rmt_set_tx_intr_en(RMT_TX_CHANNEL_1, 1);

  setupButtons();
  
  // Load saved data from JSON on startup
  loadFromJSON();

  switchMainPage();
  setMainPageVp();
}

void loop() {
  readSerialData();  // Keep serial input functionality
  if(readREM() < REM_UPPER_LIMIT) {
    readButtons();     // Add button input functionality
  }
}

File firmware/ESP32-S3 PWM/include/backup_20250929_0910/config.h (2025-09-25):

#ifndef CONFIG_H
#define CONFIG_H

#include <Arduino.h>
#include <driver/rmt.h>
#include <driver/adc.h>

// RMT Channel definitions
#define RMT_TX_CHANNEL_0  RMT_CHANNEL_0
#define RMT_TX_CHANNEL_1  RMT_CHANNEL_1

// Pin definitions
#define SENS_CUT          4
#define SENS_COAG         5
#define OPTO              6
#define REM               7
#define REM_UPPER_LIMIT   694
#define MSD1              16
#define MSD2              15
#define CTL_RLY_1         8
#define CTL_RLY_2         37
#define CTL_PWM_EN        38
#define CTL_BUZZ          36

// ADC configuration
#define ADC_CHANNEL       ADC1_CHANNEL_6
#define ADC_WIDTH         ADC_WIDTH_BIT_12
#define ADC_ATTEN         ADC_ATTEN_DB_12

// LittleFS configuration
#define FORMAT_LITTLEFS_IF_FAILED true

// Data management configuration
#define MAX_DATA_SETS 10
#define JSON_DOC_SIZE 2048
#define JSON_DATA_FILE "/data.json"

// Display Properties
#define SP80_90_A0_DEFAULT_X 210
#define SP80_90_A0_DEFAULT_Y 125

#define SPB0_C0_D0_DEFAULT_X 660
#define SPB0_C0_D0_DEFAULT_Y 125

#define KEY_CANCEL  0x00F0

// PWM configuration
const gpio_num_t PWM_0 = (gpio_num_t)1;
const gpio_num_t PWM_1 = (gpio_num_t)2;

// Button debounce configuration
const unsigned long debounceDelay = 50; // 50ms debounce delay

#endif // CONFIG_H

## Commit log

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2025-02-06 modified: .DS_Store new file: code/pwmSine.cpp new file: code/spwm.xlsx new file: code/table-sine.md new file: code/~$spwm.xlsx new file: design-controller.md modified: output-transformer.md modified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
    [sine.dwg, spwm.xlsx]
2025-02-06 modified: pic/.DS_Store new file: pic/Graph/.DS_Store modified: pic/Graph/SPWM graph.pdf modified: pic/Graph/SPWM graph.png modified: sine.bak modified: sine.dwg modified: sine.dwl modified: sine.dwl2
    [sine.dwg]
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2025-02-12 modified: log.md modified: pic/.DS_Store modified: pic/Reverse Engineering/.DS_Store new file: pic/Reverse Engineering/scope - generator output - new/bipolar/coag/standard/bi-coag-std-1.csv new file: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
    [bi-coag-std-1.csv, bi-coag-std-10.csv, bi-coag-std-12.csv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]
2025-02-17 modified: .DS_Store modified: pic/Reverse Engineering/.DS_Store renamed: pic/Reverse Engineering/scope - generator output - new/bipolar/coag/standard/bi-coag-std-1.csv -> pic/Reverse Engineering/scop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
    [bi-coag-standard-10.csv, bi-coag-standard-20.csv, bi-coag-standard-30.csv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]
2025-02-18 modified: .DS_Store modified: log.md new file: pic/Reverse Engineering/scope - generator output - new/monopolar/cut/pure/input - output/mono-cut-pure-100-1.csv new file: pic/Reverse Engineering/scope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
    [mono-cut-pure-1.csv, mono-cut-pure-10.csv, mono-cut-pure-100-1.csv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]
2025-02-20 modified: pic/.DS_Store new file: pic/Graph/55fbba17-8e88-43f0-ab2f-7c834b2ff554 copy.ezdraw modified: pic/Reverse Engineering/.DS_Store new file: pic/Reverse Engineering/scope - mainboard/input tran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
    [input transformer RE.csv, input-output transformer button.csv, output timer 555 - filtered by cap.csv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]
2025-02-26 modified: .DS_Store new file: hardware/MSD-1.0/#auto_saved_files# new file: hardware/MSD-1.0/MSD-1.0-backups/MSD-1.0-2025-02-24_160102.zip new file: hardware/MSD-1.0/MSD-1.0-backups/MSD-1.0-2025-02-2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
    [MSD-1.0.kicad_pcb, MSD-1.0.kicad_sch, REM-1.0.kicad_pcb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]
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2025-03-05 deleted: hardware/MSD-1.0/#auto_saved_files# new file: hardware/MSD-1.0/MSD-1.0 BoM.csv new file: hardware/MSD-1.0/MSD-1.0-B_Cu.gbr new file: hardware/MSD-1.0/MSD-1.0-B_Mask.gbr new file: hardware/MS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
    [MSD-1.0 BoM.csv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]
2025-04-14 modified: .DS_Store deleted: hardware/MSD-1.0/MSD-1.0-backups/MSD-1.0-2025-02-25_161819.zip deleted: hardware/MSD-1.0/MSD-1.0-backups/MSD-1.0-2025-02-25_162448.zip deleted: hardware/MSD-1.0/MSD-1.0-b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
    [MSD-1.0 BoM.csv, MSD-1.0.kicad_pcb, MSD-1.0.kicad_sch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]
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2025-04-14 deleted: hardware/MSD-1.0/MSD-1.0-backups/MSD-1.0-2025-03-24_113503.zip new file: hardware/MSD-1.0/MSD-1.0-backups/MSD-1.0-2025-04-14_090414.zip new file: hardware/MSD-2.0/MSD-2.0-backups/MSD-2.0-202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
    [PS-1.0.kicad_pcb]
2025-04-15 new file: hardware/Gain/Gain-B_Cu.gbr new file: hardware/Gain/Gain-B_Mask.gbr new file: hardware/Gain/Gain-B_Paste.gbr new file: hardware/Gain/Gain-B_Silkscreen.gbr new file: hardware/Gain/Gain-Edge_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
    [Gain-B_Cu.gbr, Gain-B_Mask.gbr, Gain-B_Paste.gbr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]
2025-04-16 deleted: hardware/Gain/Gain-backups/Gain-2025-04-14_115147.zip new file: hardware/Gain/Gain-backups/Gain-2025-04-15_120154.zip deleted: hardware/MSD-1.0/MSD-1.0-backups/MSD-1.0-2025-03-24_134332.zip 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
    [MSD-1.0.kicad_pcb, MSD-1.0.kicad_sch, PS-1.0.kicad_pcb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]
2025-04-17 new file: hardware/Gain/Gain-backups/Gain-2025-04-17_151501.zip deleted: hardware/MSD-1.0/MSD-1.0-backups/MSD-1.0-2025-03-25_151318.zip deleted: hardware/MSD-1.0/MSD-1.0-backups/MSD-1.0-2025-03-26_08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
    [MSD-1.0.kicad_pcb, PS-1.0.kicad_pcb, PS-1.0.kicad_sch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]
2025-04-28 new file: .~BoM.xlsx new file: BoM.xlsx new file: hardware/BoM.xlsx deleted: hardware/MSD-1.0/MSD-1.0-backups/MSD-1.0-2025-03-26_092035.zip deleted: hardware/MSD-1.0/MSD-1.0-backups/MSD-1.0-2025-03-2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
    [BoM.xlsx, MSD-1.0.csv, MSD-1.0.kicad_pcb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]
2025-04-29 modified: .DS_Store modified: BoM.xlsx modified: hardware/MSD-1.0/MSD-1.0-B_Cu.gbr modified: hardware/MSD-1.0/MSD-1.0-B_Mask.gbr modified: hardware/MSD-1.0/MSD-1.0-B_Paste.gbr modified: hardware/MSD-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
    [BoM.xlsx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]
2025-05-03 modified: .DS_Store modified: BoM.xlsx new file: firmware/ESP32-S3 PWM/.gitignore new file: firmware/ESP32-S3 PWM/include/README new file: firmware/ESP32-S3 PWM/lib/README new file: firmware/ESP32-S3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
    [BoM.xlsx, RigolDS0.csv, RigolDS1.csv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]
2025-05-05 modified: .DS_Store modified: README.md modified: pic/.DS_Store new file: pic/PWM/400kHz/RMT/RMT-00.csv new file: pic/PWM/400kHz/RMT/RMT-00.png new file: pic/PWM/400kHz/RMT/RMT-01.csv new file: pic/P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
    [RMT-00.csv, RMT-01.csv, RMT-02.csv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]
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2025-05-05 modified: firmware/ESP32-S3 PWM/src/main.cpp modified: pic/.DS_Store new file: pic/PWM/blend-cut-1/blend-cut-1-10.csv new file: pic/PWM/blend-cut-1/blend-cut-1-10.png new file: pic/PWM/blend-cut-1/bl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
    [blend-cut-1-10.csv, blend-cut-1-100.csv, blend-cut-1-20.csv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]
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2025-05-06 modified: .DS_Store modified: README.md deleted: hardware/MSD-1.0/MSD-1.0 BoM.csv deleted: hardware/MSD-1.0/MSD-1.0-backups/MSD-1.0-2025-04-08_110759.zip deleted: hardware/MSD-1.0/MSD-1.0-backups/MSD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
    [MSD-1.0 BoM.csv, MSD-1.0.kicad_pcb, MSD-1.0.kicad_sch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]
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2025-05-06 modified: .DS_Store modified: README.md renamed: hardware/PS-2.0/PS-2.0-backups/PS-2.0-2025-05-06_104122.zip -> hardware/PS-2.0/PS-2.0-backups/PS-2.0-2025-05-07_010425.zip new file: hardware/REM-4.0/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
    [REM-4.0.kicad_sch]
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2025-09-30 new file: firmware/ESP32-S3 PWM/include/buzzer.h modified: firmware/ESP32-S3 PWM/include/hardware_control.h new file: firmware/ESP32-S3 PWM/src/buzzer.cpp modified: firmware/ESP32-S3 PWM/src/display_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
    [buzzer.cpp, display_comm.cpp, hardware_control.cpp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]
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2026-01-07 modified: .DS_Store new file: CAD/enclosure.dwg new file: CAD/front-panel.dwg new file: CAD/socket-bipolar-v1.dwg new file: CAD/socket-monopolar-v1.dwg new file: CAD/socket-re-v1.dwg new file: CAD/te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
    [CTL-4.1.kicad_pcb, Ferrite Transformer Calculation.xlsx, PS-4.0.kicad_pcb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]
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
